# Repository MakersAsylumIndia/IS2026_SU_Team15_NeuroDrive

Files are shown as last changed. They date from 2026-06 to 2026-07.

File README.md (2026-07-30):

# IS2026 Spring - NeuroDrive

EMG-controlled robot car that uses muscle signals to drive, turn, and navigate without any traditional controller. By converting tiny electrical impulses from the human body into movement commands, we bridge the gap between humans and machines in a fun and innovative way.
"Move your muscles. Move the machine." 💪🤖

# Prototype Photos

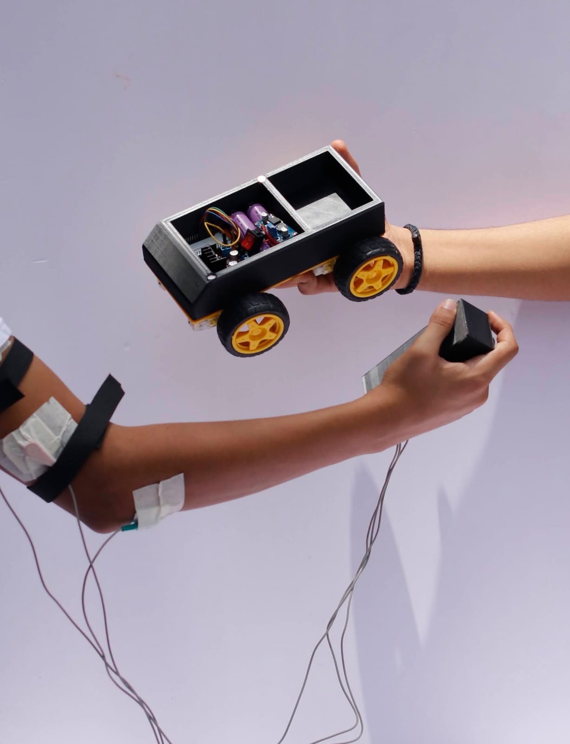
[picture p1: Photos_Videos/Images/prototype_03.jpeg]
Prototype


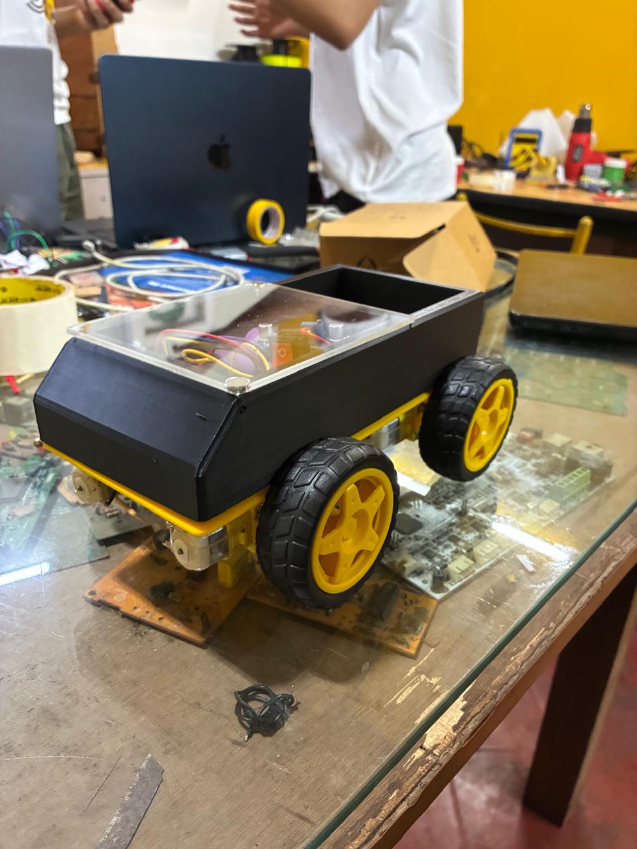
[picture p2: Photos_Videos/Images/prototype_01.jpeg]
Prototype


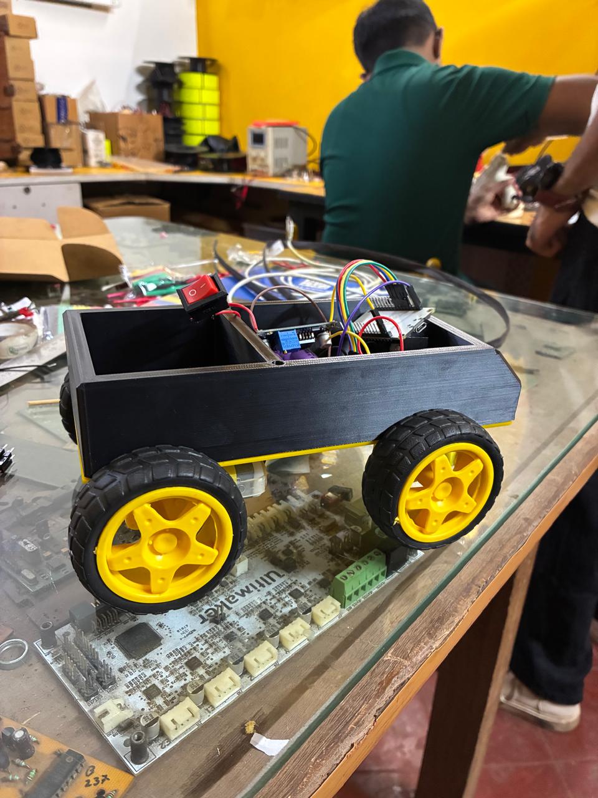
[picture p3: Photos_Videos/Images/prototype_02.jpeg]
Prototype


# CAD RENDER

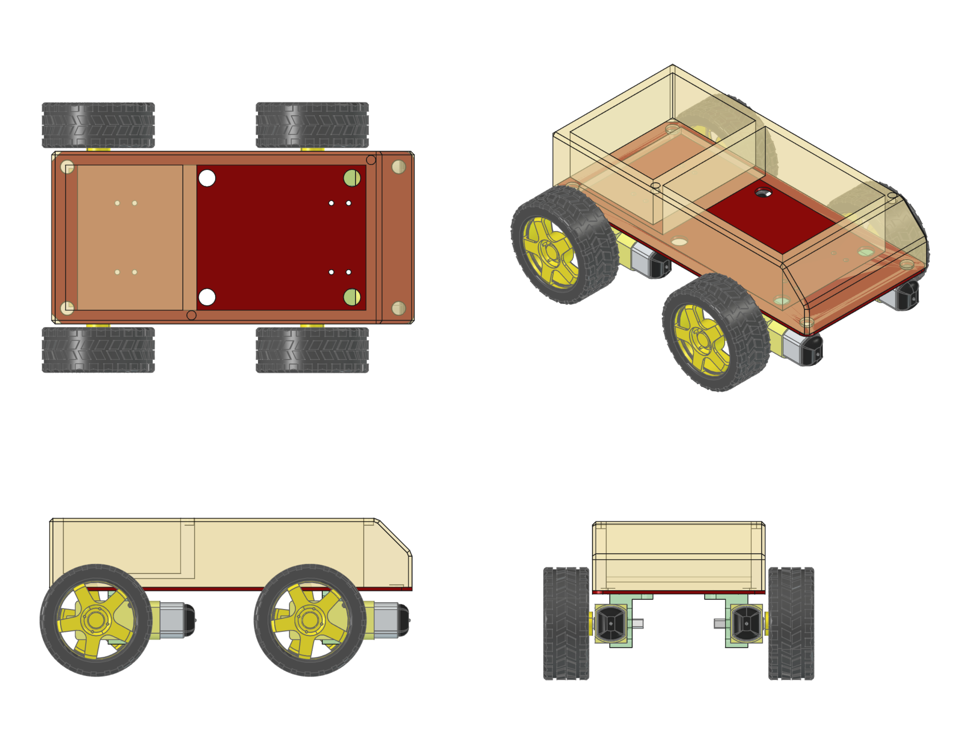
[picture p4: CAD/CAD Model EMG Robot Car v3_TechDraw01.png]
NeuroDrive CAD Render


## License

Licenses

<a href="LICENSE.md">Open Source Licenses Facts</a>

#### Hardware
CERN Open Hardware License Version 2 - Strongly Reciprocal ([CERN-OHL-S-2.0](https://spdx.org/licenses/CERN-OHL-S-2.0.html)).

#### Software
MIT open source [license](http://opensource.org/licenses/MIT).

#### Documentation:
<br />This work is licensed under a <a rel="license" href="http://creativecommons.org/licenses/by/4.0/">Creative Commons Attribution 4.0 International License</a>.

---

## 📬 Contact/Team

> _List team members and contact emails or GitHub profiles._

[Aaliya Thakker](https://github.com/Aaliya17)

[Abhay Gupta](https://github.com/abhiguppta-spec)

[Kashvi Mummaneni](https://github.com/Kashvi-Mm)

[Reyansh Bhimrajka](https://github.com/rbhimrajka)

[Maker's Asylum](https://github.com/makersasylum)

[Anool](https://github.com/Anool)
> 
> ---

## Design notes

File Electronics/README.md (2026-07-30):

The Circuit Diagram can be viewed at this URL :
https://app.cirkitdesigner.com/project/f359c818-f60a-4dbf-a67e-0d322c175c05

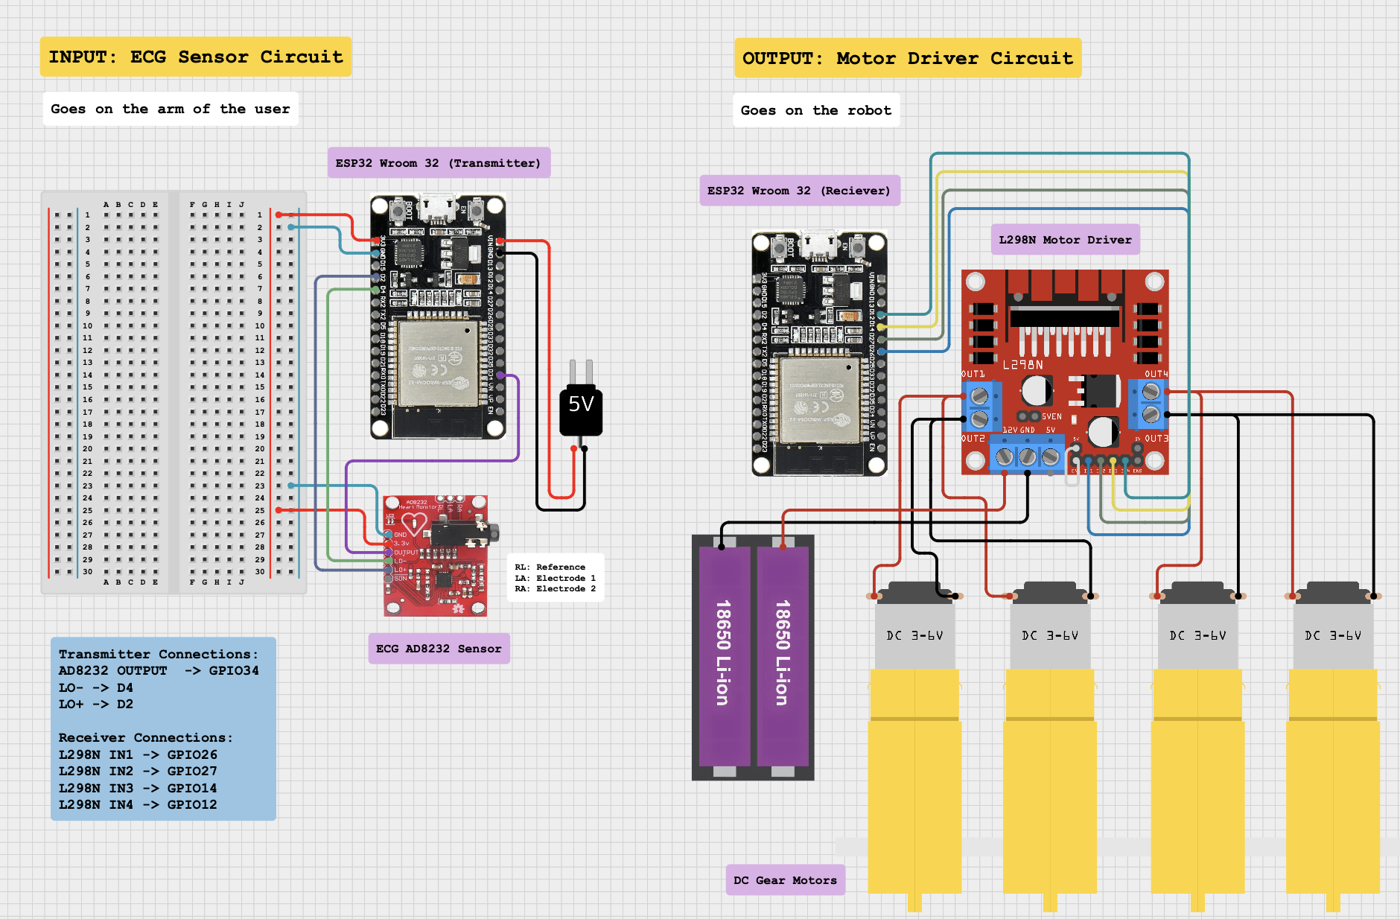
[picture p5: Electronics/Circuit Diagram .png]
NeuroDrive CAD Render


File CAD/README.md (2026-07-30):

# CAD RENDER

- 3D print the ENCLOSURE STEP file from the 3d_prints folder
- 3D print the MOTOR MOUNTS STEP files from the 3d_prints folder (two each for left and right)
- Laser cut the CHASSIS base from the laser_cut folder (Acrylic, 3mm or 5mm)
- Use 8mm magnets to attach ENCLOSURE to CHASSIS

NeuroDrive CAD Render

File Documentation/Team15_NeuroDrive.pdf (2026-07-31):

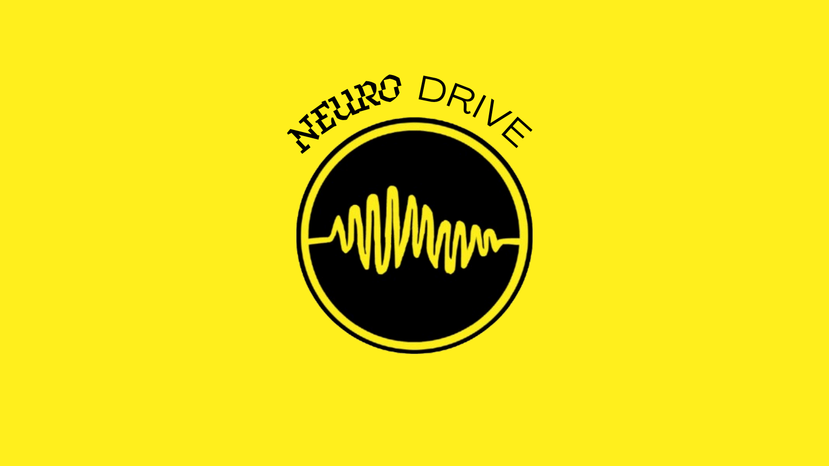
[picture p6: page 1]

# DRIVE

# NEURO

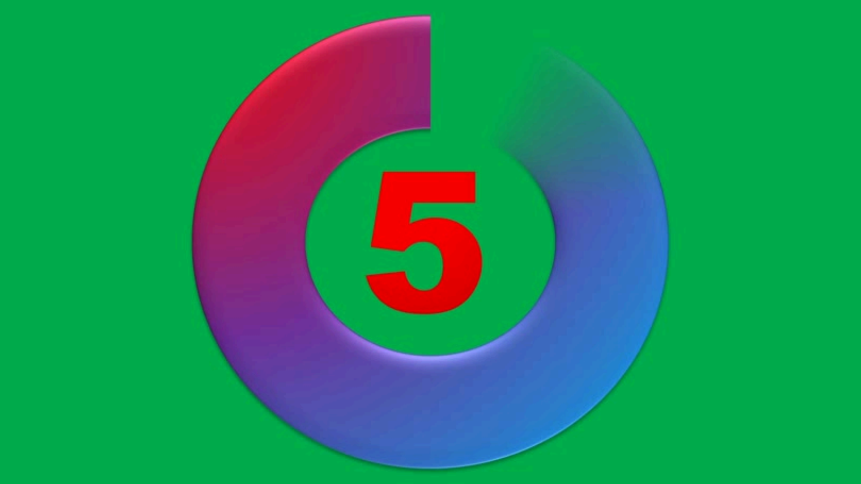
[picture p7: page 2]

# The World'

s Most Revolutionary, Groundbreaking,

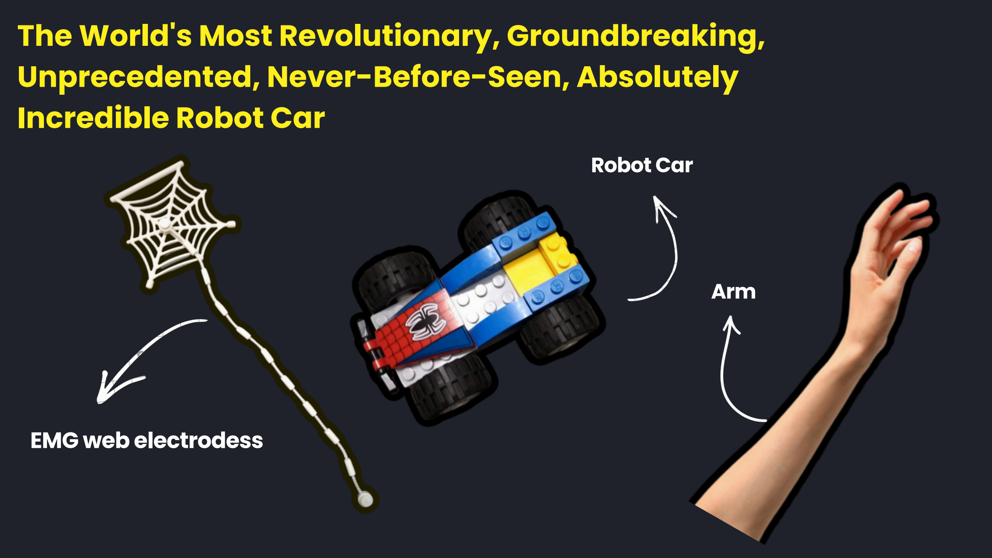
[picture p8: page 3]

# Unprecedented, Never-Before-Seen, Absolutely Incredible Robot Car

# EMG web electrodess

# Robot Car

# Arm

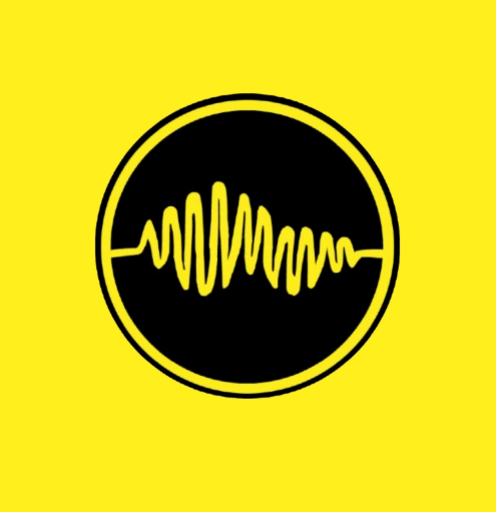
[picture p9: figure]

# MEET OURTEAM

# Aaliya Thakker

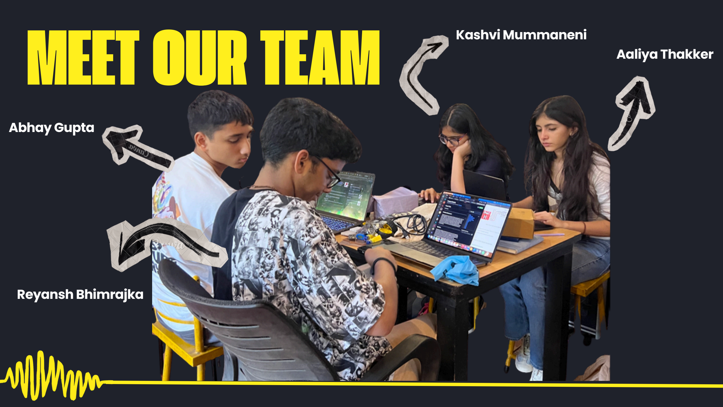
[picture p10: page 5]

# Kashvi Mummaneni

# Abhay Gupta

# Reyansh Bhimrajka

# THE PROBLEM

Everyday electronic devices like phones, remotes, controllers, robots; require hands,

# fingers, and precise motor control to operate. For people with conditions like paralysis, muscular dystrophy, ALS, or limb loss, this creates a complete barrier to

independent interaction with technology.

# However, most assistive technologies are either too expensive, too complex, or

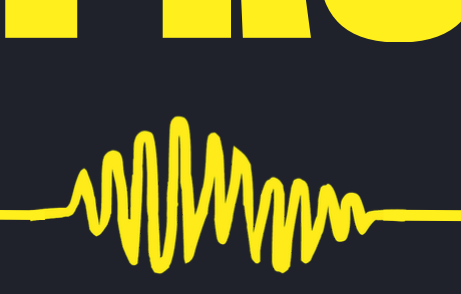
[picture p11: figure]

require full physical movement to operate.

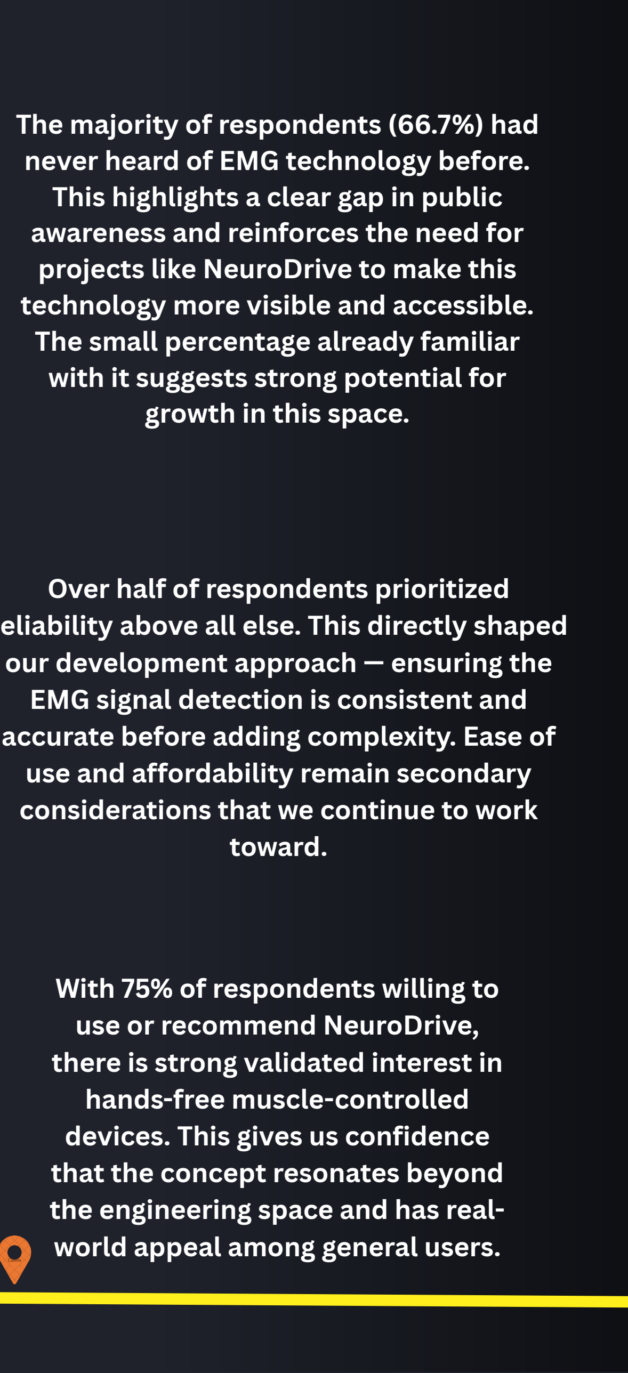
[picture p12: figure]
The majority of respondents (66.7%) had never heard of EMG technology before. This highlights a clear gap in public awareness and reinforces the need for projects like NeuroDrive to make this technology more visible and accessible. The small percentage already familiar with it suggests strong potential for growth in this space.; Over half of respondents prioritized; our development approach — ensuring the EMG signal detection is consistent and; use and affordability remain secondary considerations that we continue to work toward.; With 75% of respondents willing to use or recommend NeuroDrive, there is strong validated interest in hands-free muscle-controlled devices. This gives us confidence that the concept resonates beyond the engineering space and has real- world appeal among general users.
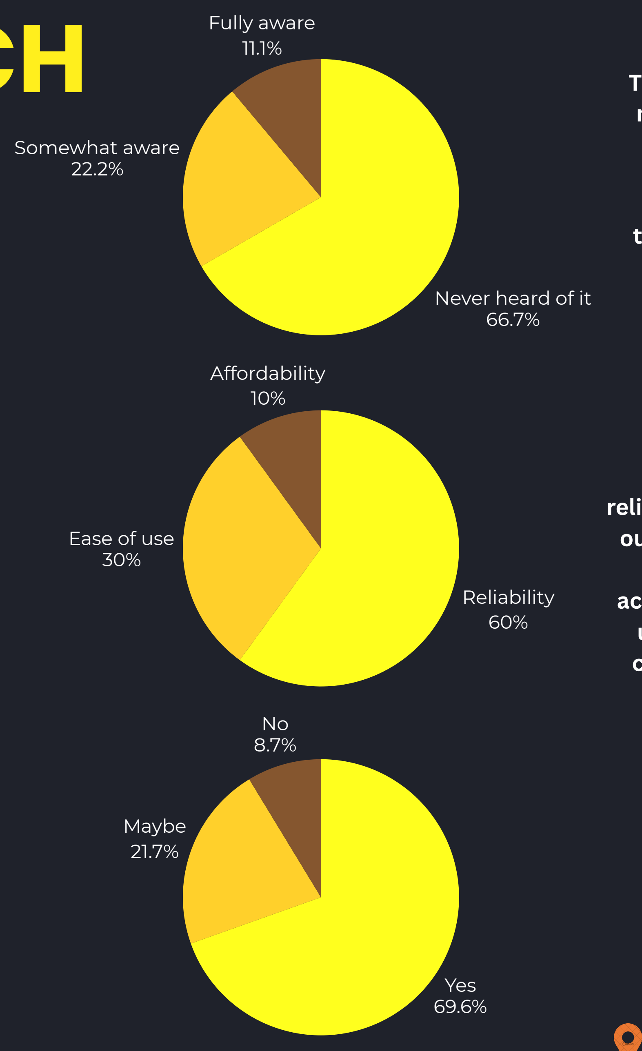
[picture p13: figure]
Yes 69.6%; Maybe 21.7%; Reliability 60%; Ease of use 30%; Affordability 10%; Never heard of it 66.7%; Somewhat aware 22.2%; Fully aware 11.1%
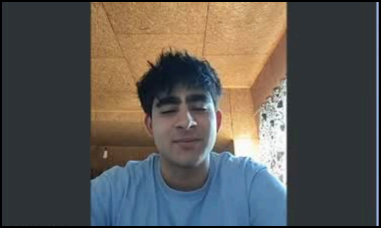
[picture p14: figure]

reliability above all else. This directly shaped

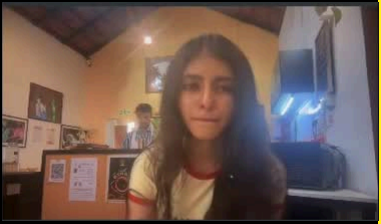
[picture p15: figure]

accurate before adding complexity. Ease of

# PRIMARY RESEARCH

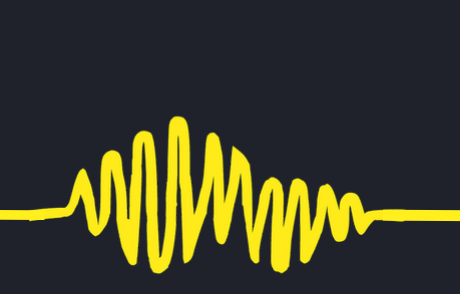
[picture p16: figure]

N

e

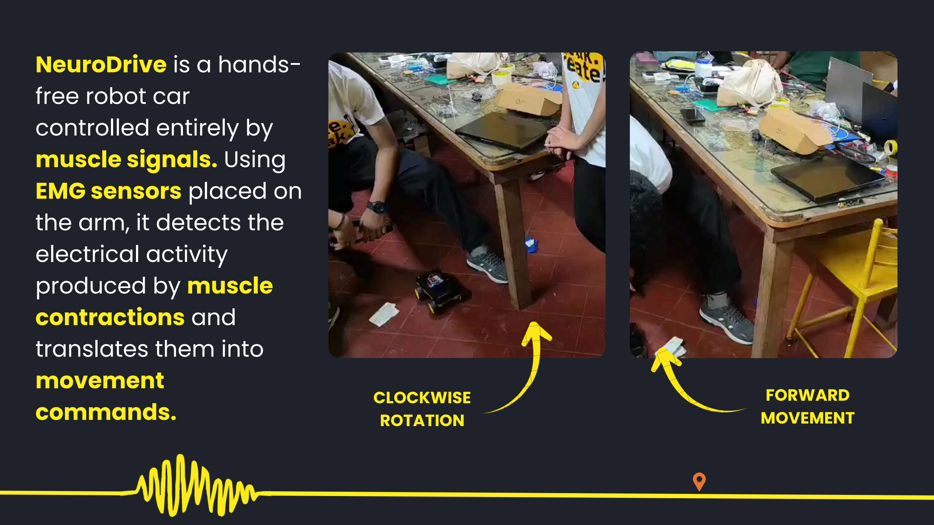
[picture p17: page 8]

u

r

o

D

r

i

v

# e is

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
# olle

d

e

n

# tir

# ely

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
# sin

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
# pla

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
, it

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
# ele

c

t

# ric

# al a

c

# tivit

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
# sla

t

e

s

t

h

e

# m in

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
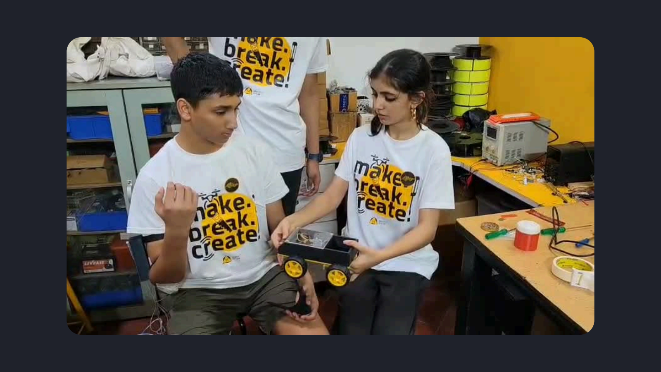
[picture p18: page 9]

# HARDWARE BREAKDOWN

## Li-ion Batteries

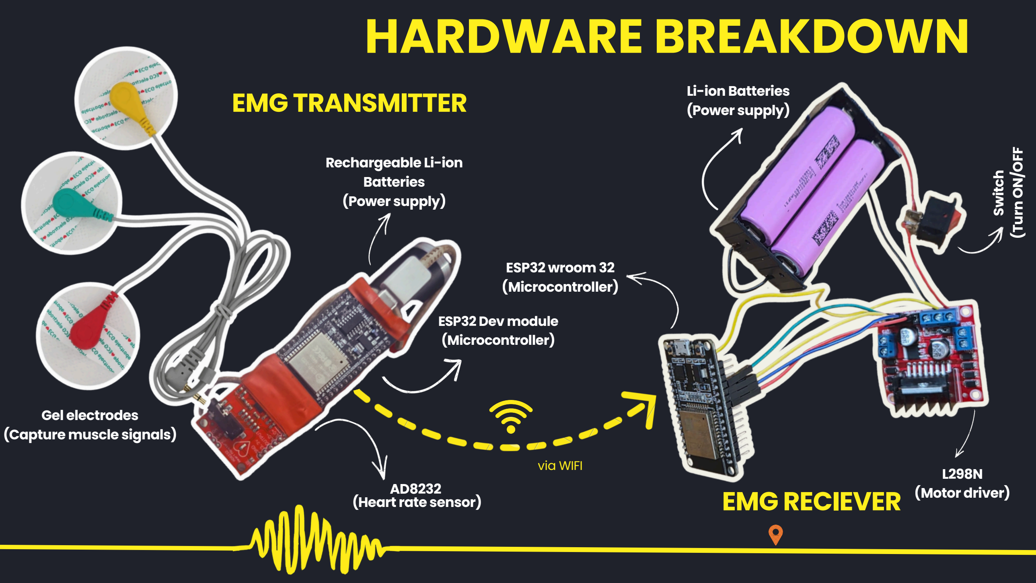
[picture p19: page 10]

L298N

## (Motor driver)

## ESP32 wroom32 (Microcontroller)

## (Power supply)

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
# EMG RECIEVER

# EMG TRANSMITTER

## ESP32 Devmodule (Microcontroller)

## Rechargeable Li-ion Batteries (Power supply)

## Gel electrodes (Capturemuscle signals)

AD8232

## (Heart rate sensor)

### via WIFI

# TECHNICAL OVERVIEW OF HOW NEURO DRIVE WORKS

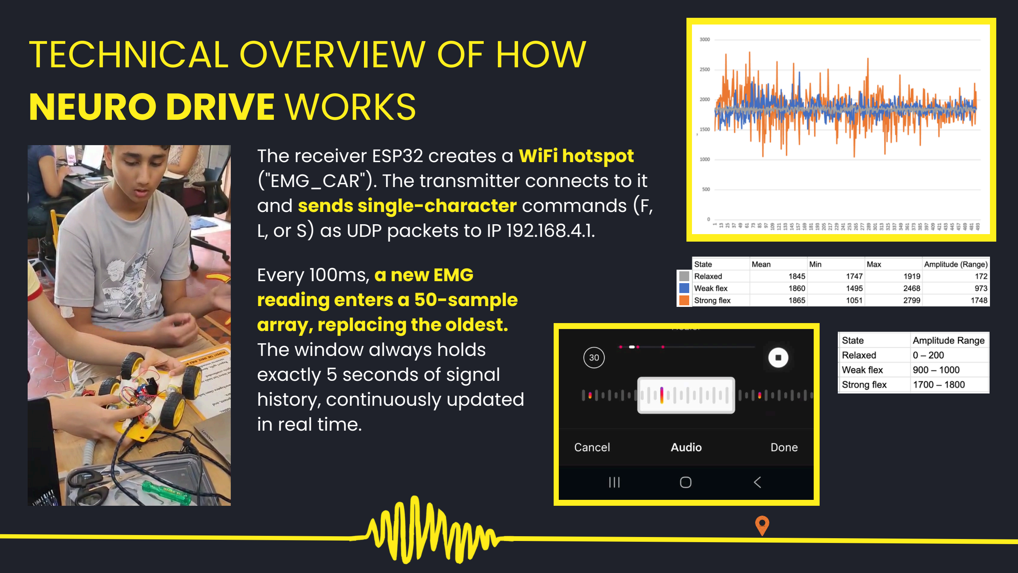
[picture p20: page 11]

# The receiver ESP32 creates a WiFi hotspot ("EMG_CAR"). The transmitter connects to it

and sends single-character commands (F, L, or S) as UDP packets to IP 192.168.4.1.

# Every 100ms, a new EMG reading enters a 50-sample

array, replacing the oldest.

# The window always holds exactly 5 seconds of signal history, continuously updated

in real time.

# DESIGN

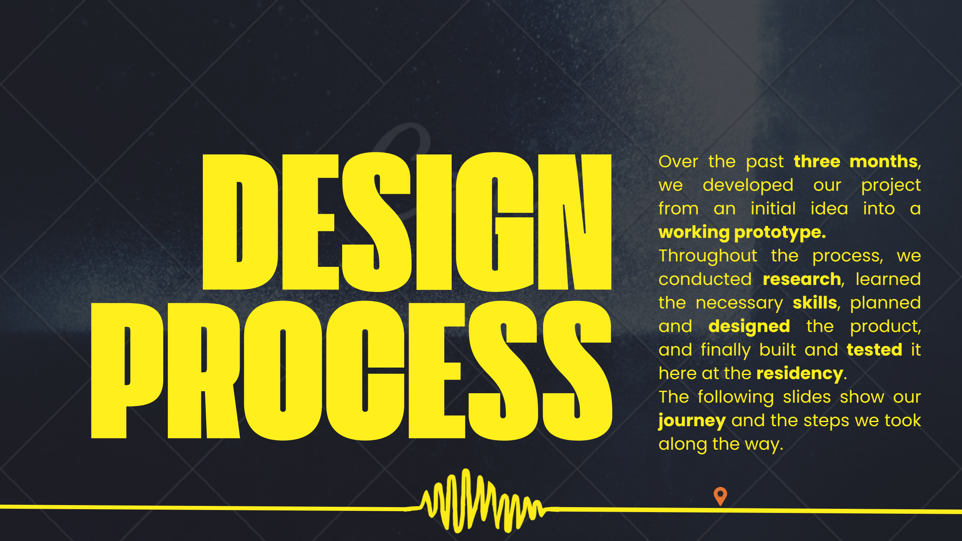
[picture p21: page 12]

Over the past three months,

# we developed our project from an initial idea into a

working prototype.

# Throughout the process, we conducted research, learned the necessary skills, planned

and designed the product,

# and finally built and tested it

here at the residency.

# The following slides show our journey and the steps we took

along the way.

# PROCESS

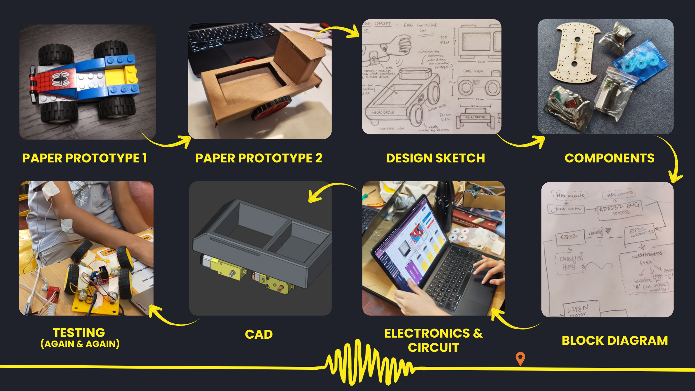
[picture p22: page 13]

PAPER PROTOTYPE 1 | PAPER PROTOTYPE 2 | DESIGN SKETCH | COMPONENTS

# BLOCK DIAGRAM

# ELECTRONICS & CIRCUIT

TESTING | CAD

## (AGAIN & AGAIN)

# ECG SENSOR

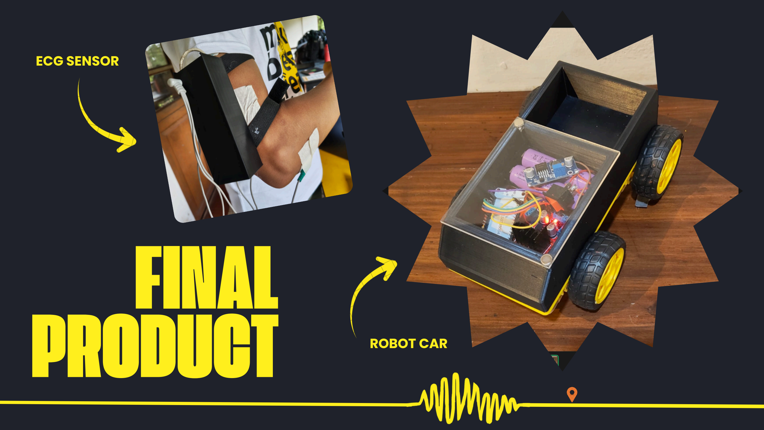
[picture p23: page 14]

# ROBOT CAR

# FINAL PRODUCT

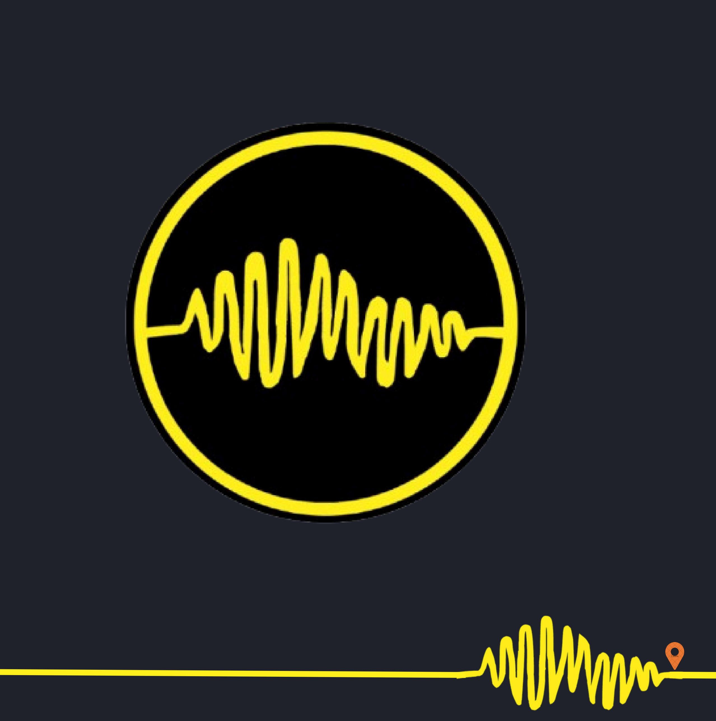
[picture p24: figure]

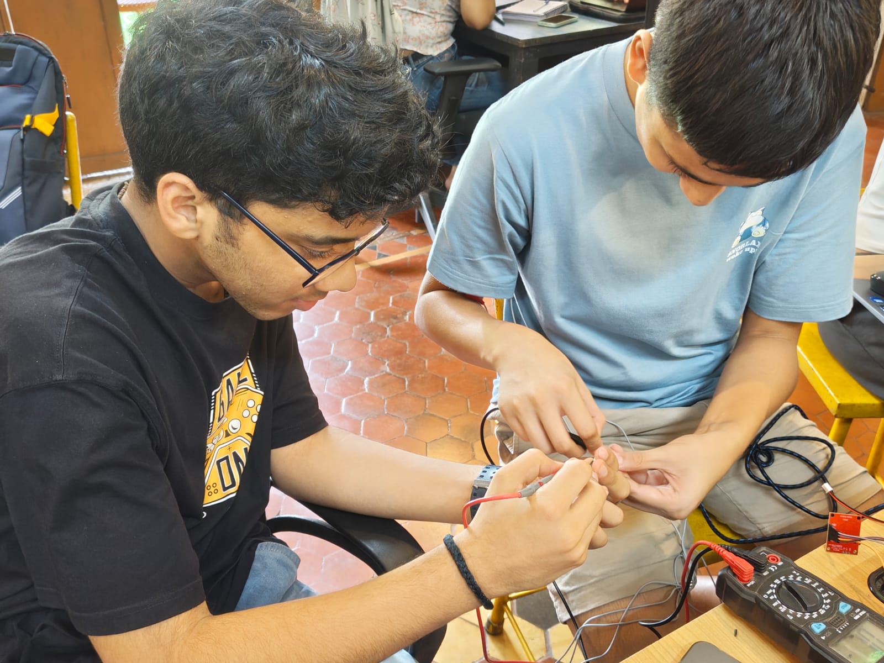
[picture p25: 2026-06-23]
Photos_Videos/Images/Electronics.jpeg

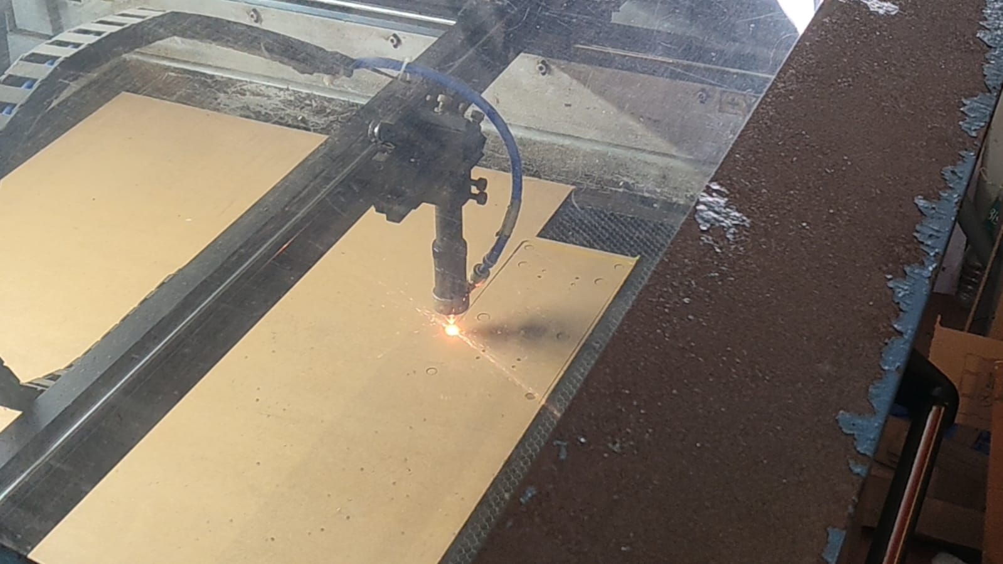
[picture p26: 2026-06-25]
Photos_Videos/Images/Laser Cutting Chassis.jpeg

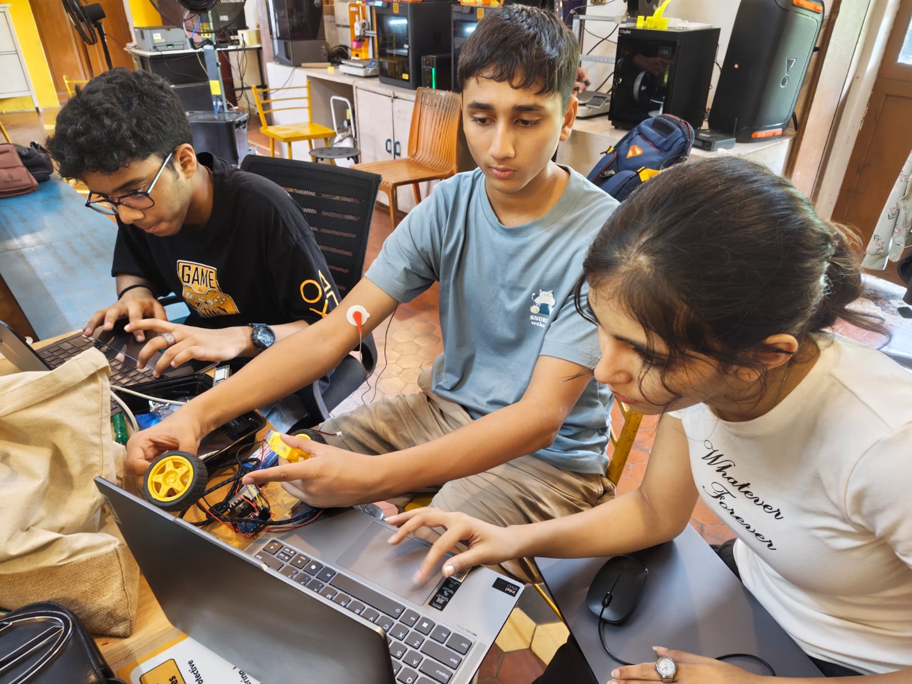
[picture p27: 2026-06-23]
Photos_Videos/Images/Electronics 2.jpeg

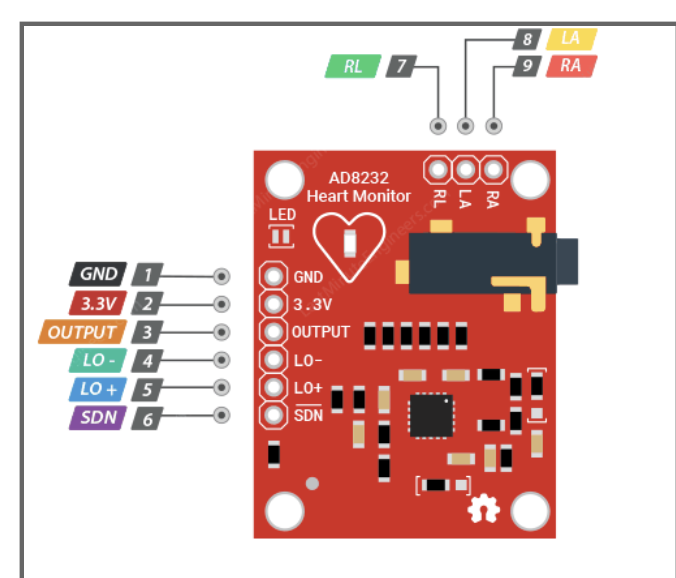
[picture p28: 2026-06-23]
Electronics/AD8232 Pinouts.png

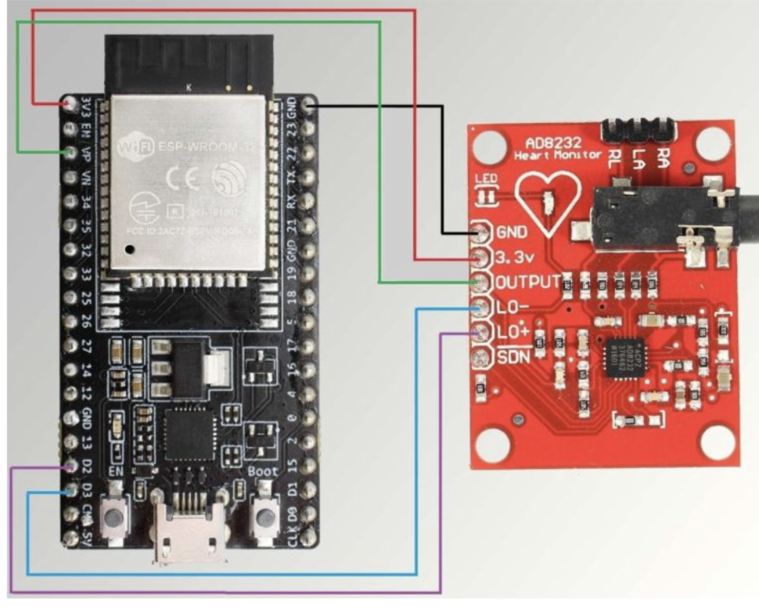
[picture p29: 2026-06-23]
Electronics/ESP32 to AD8232 Connection .png

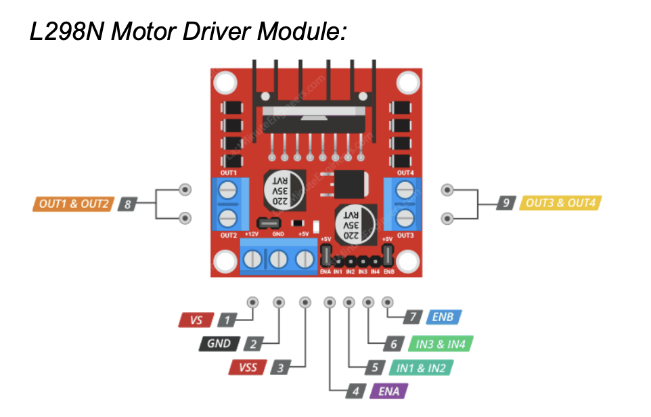
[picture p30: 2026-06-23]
Electronics/L298N Driver Pinouts.png

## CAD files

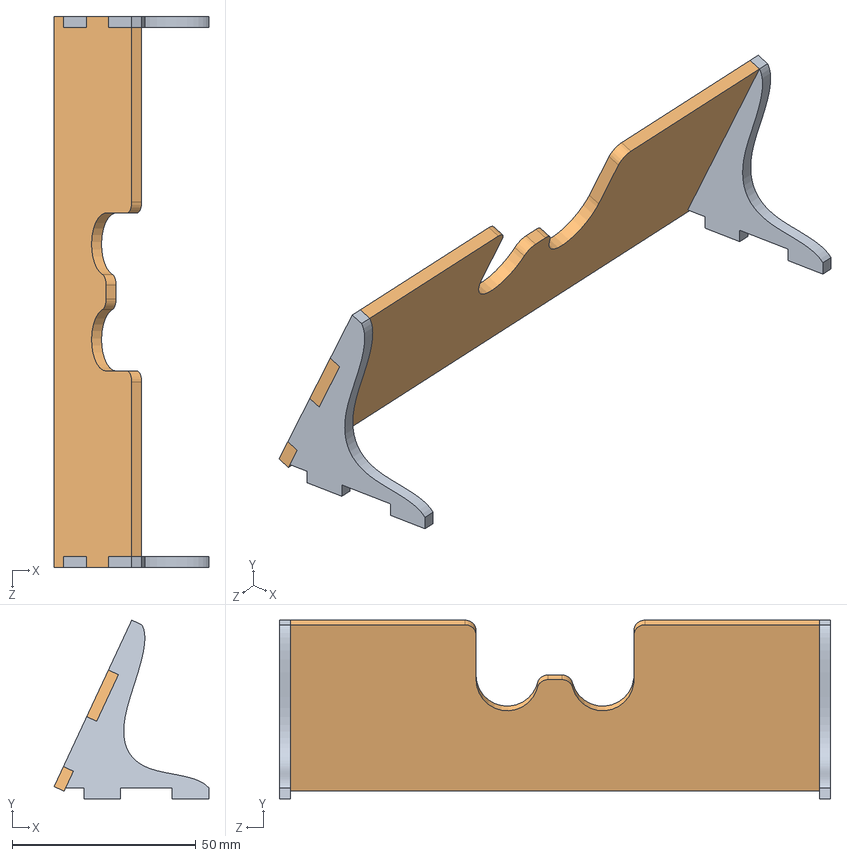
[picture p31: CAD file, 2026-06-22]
CAD/assets/sumo-bot-15x15cm-1.snapshot.4/Solid/Defensa.SLDASM
42.1 x 48.7 x 150.0 mm
SoporteDefensa_dm x 2
Defensa_dm

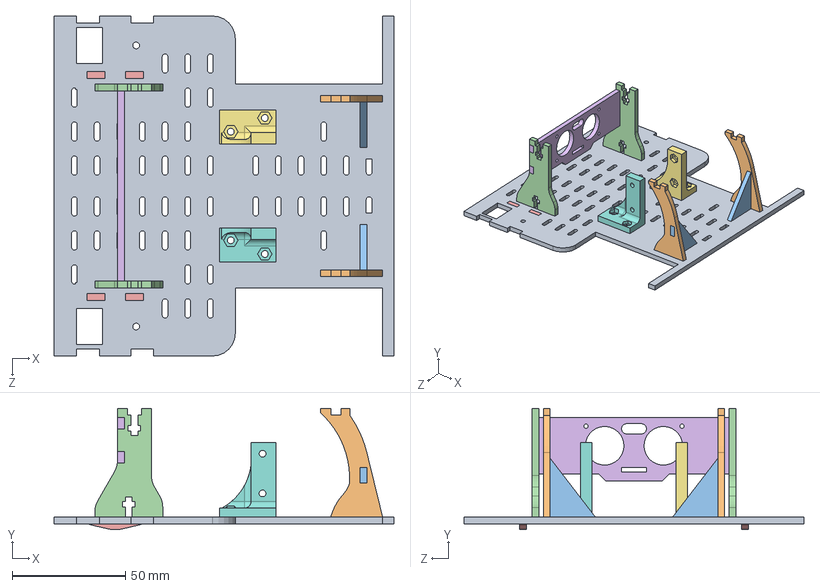
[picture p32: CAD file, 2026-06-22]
CAD/assets/sumo-bot-15x15cm-1.snapshot.4/Solid/Base_inferior.SLDASM
150.0 x 53.5 x 150.0 mm
base1_dm
SoporteBateria_dm x 2
NervioBateria_dm x 2
SoporteArduino1_dm x 2
Ski x 2
SoporteSensorUltrasonidos
SoporteMotor
SimetríaSoporteMotor

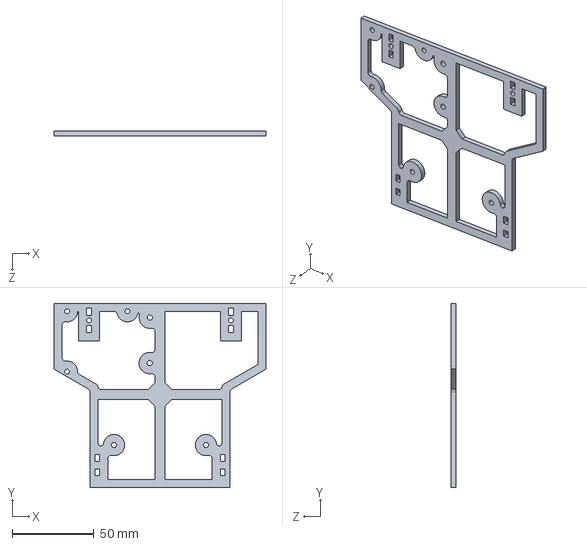
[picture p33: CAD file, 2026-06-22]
CAD/assets/sumo-bot-15x15cm-1.snapshot.4/Solid/Base_superior.SLDASM
130.0 x 113.1 x 3.00 mm

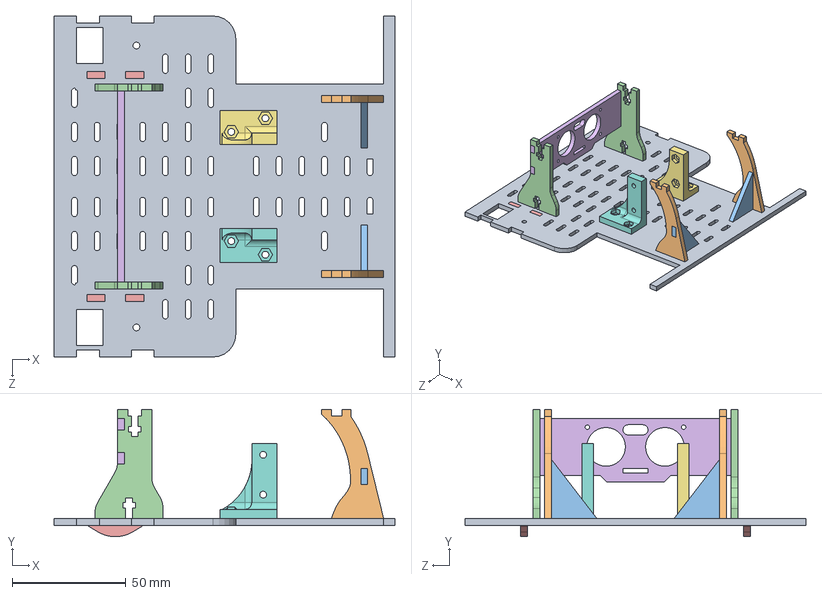
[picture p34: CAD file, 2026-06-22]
CAD/assets/sumo-bot-15x15cm-1.snapshot.4/Solid/Base1_electronica.SLDASM
150.0 x 56.0 x 150.0 mm
base1_dm
SoporteBateria_dm x 2
NervioBateria_dm x 2
SoporteArduino1_dm x 2
Ski x 2
SoporteSensorUltrasonidos
SoporteMotor
SimetríaSoporteMotor

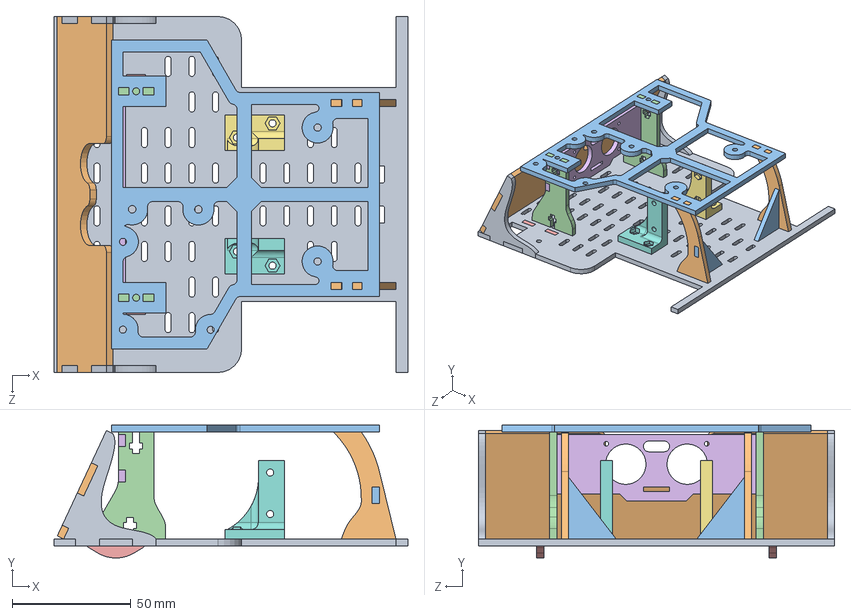
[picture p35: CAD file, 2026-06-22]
CAD/assets/sumo-bot-15x15cm-1.snapshot.4/Solid/_Sumo.SLDASM
149.0 x 56.0 x 150.0 mm
base1_dm
SoporteBateria_dm x 2
NervioBateria_dm x 2
SoporteArduino1_dm x 2
Ski x 2
SoporteSensorUltrasonidos
SoporteMotor
SimetríaSoporteMotor
SoporteDefensa_dm x 2
Defensa_dm
base2_dm

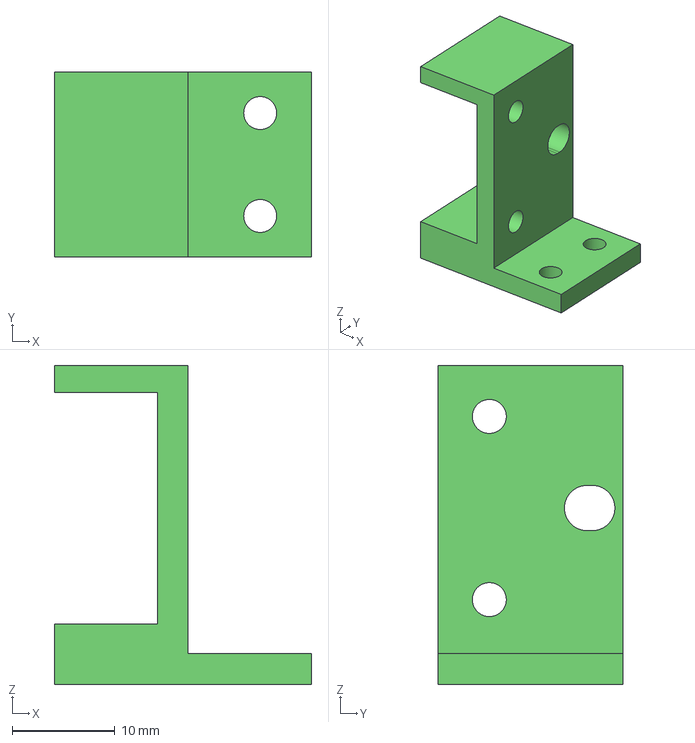
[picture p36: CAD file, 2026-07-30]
CAD/3d_prints/gesture_bot-motor_mount_02.step
25.0 x 18.0 x 31.0 mm

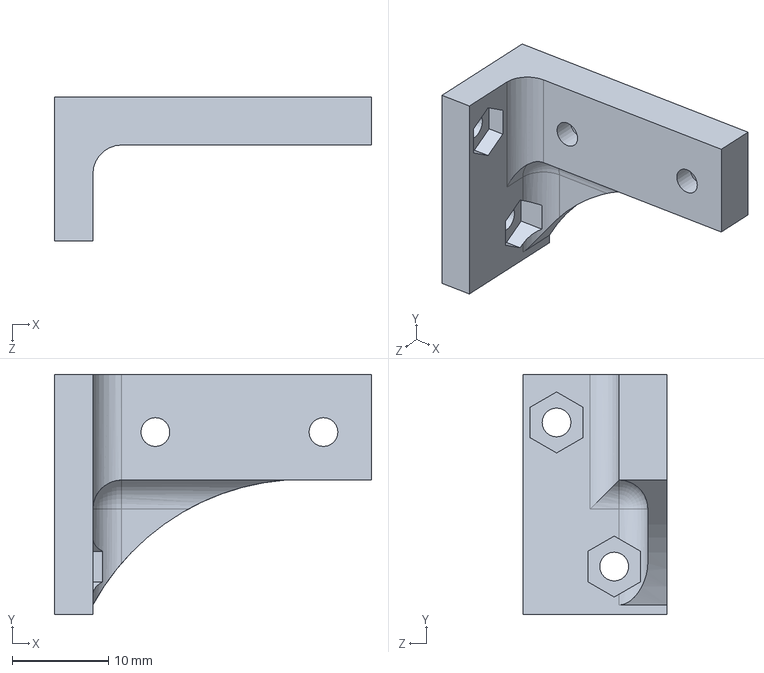
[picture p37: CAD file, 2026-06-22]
CAD/assets/sumo-bot-15x15cm-1.snapshot.4/Solid/SoporteMotor.SLDPRT
33.0 x 25.0 x 15.0 mm

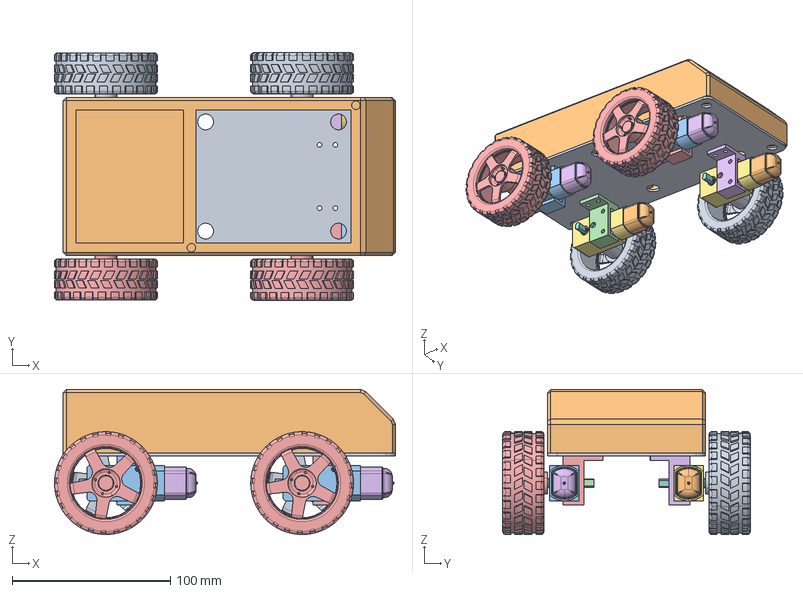
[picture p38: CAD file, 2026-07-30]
CAD/CAD Model EMG Robot Car v3.FCStd
215.5 x 156.5 x 91.6 mm
Chassis
Enclosure
Real Bo Motor Gear Box004
Shaft004
Real Wheel004
Real Bo Motor Frame012
Real Bo Motor Gear Box
Shaft
Real Wheel
Real Bo Motor Frame
Real Bo Motor Gear Box005
Shaft005
Real Wheel005
Real Bo Motor Frame013
Real Bo Motor Gear Box006
Shaft006
Real Wheel006
Real Bo Motor Frame014
motor_mount_01
motor_mount_03 (Mirror #1)
motor_mount_02
motor_mount_04 (Mirror #1)

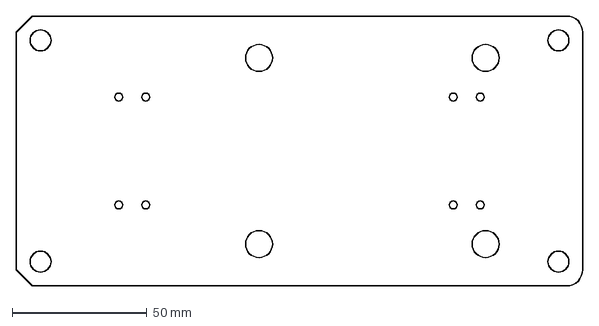
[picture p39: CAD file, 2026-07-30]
CAD/laser_cut/gesture_bot-Chassis_2DView.dxf
210.0 x 100.0 mm

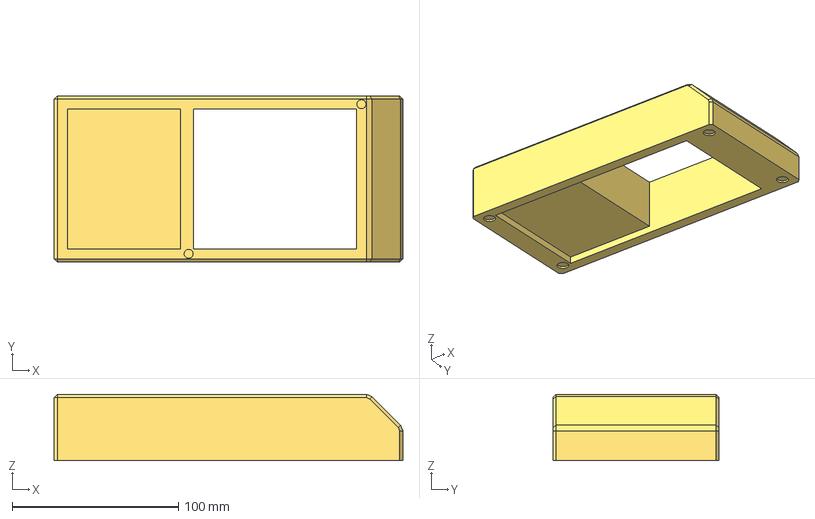
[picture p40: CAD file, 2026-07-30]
CAD/3d_prints/CAD Model EMG Robot Car v3-Enclosure.step
210.0 x 100.0 x 40.0 mm

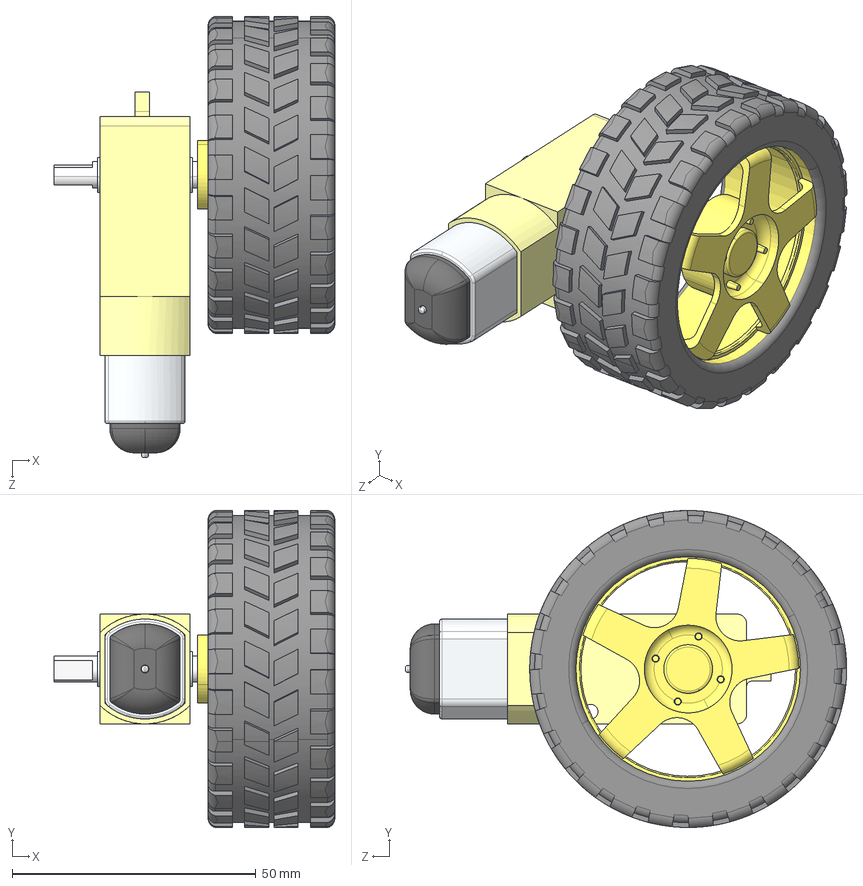
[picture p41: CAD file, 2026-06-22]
CAD/assets/Real Bo Motor With Wheel.step
57.6 x 65.0 x 90.5 mm
Real Bo Motor Gear Box
Shaft
Real Wheel
Real Bo Motor Frame

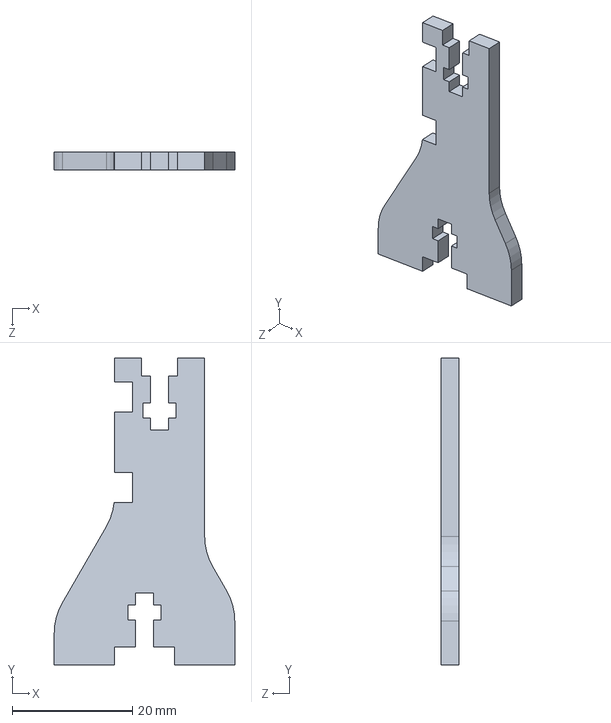
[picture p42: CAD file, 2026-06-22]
CAD/assets/sumo-bot-15x15cm-1.snapshot.4/Solid/SoporteArduino1_dm.SLDPRT
30.0 x 51.0 x 3.00 mm

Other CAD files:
CAD/assets/sumo-bot-15x15cm-1.snapshot.4/Files/Defensa_dm.DWG
CAD/assets/sumo-bot-15x15cm-1.snapshot.4/Files/SimetríaSoporteMotor.STL
CAD/3d_prints/gesture_bot-motor_mount_01.step
CAD/assets/sumo-bot-15x15cm-1.snapshot.4/Files/SoporteArduino1_dm.DWG
CAD/assets/sumo-bot-15x15cm-1.snapshot.4/Solid/SimetríaSoporteMotor.SLDPRT
CAD/assets/sumo-bot-15x15cm-1.snapshot.4/Files/SoporteBateria_dm.DWG
CAD/assets/18650 Battery Holder v5.step
CAD/assets/sumo-bot-15x15cm-1.snapshot.4/Files/NervioBateria_dm.DWG
CAD/assets/sumo-bot-15x15cm-1.snapshot.4/Files/Ski.DWG
CAD/assets/sumo-bot-15x15cm-1.snapshot.4/Files/SoporteDefensa_dm.DWG
CAD/assets/sumo-bot-15x15cm-1.snapshot.4/Files/SoporteMotor.STL
CAD/assets/sumo-bot-15x15cm-1.snapshot.4/Files/SoporteSensorUltrasonidos.DWG
CAD/assets/sumo-bot-15x15cm-1.snapshot.4/Files/base1_dm.DWG
CAD/assets/sumo-bot-15x15cm-1.snapshot.4/Files/base2_dm.DWG
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

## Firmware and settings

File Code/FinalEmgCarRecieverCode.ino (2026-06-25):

// EMG Car Receiver — ESP32 WROOM-32 + L298N
//
// L298N IN1 -> GPIO26  (Left motor)
// L298N IN2 -> GPIO27  (Left motor)
// L298N IN3 -> GPIO14  (Right motor)
// L298N IN4 -> GPIO12  (Right motor)
// L298N ENA -> 5V (always enabled)
// L298N ENB -> 5V (always enabled)

#include "BluetoothSerial.h"
BluetoothSerial bt;

void setup() {
  Serial.begin(115200);
  bt.begin("EMG_CAR");
  Serial.print("MAC: ");
  Serial.println(ESP.getEfuseMac(), HEX);
}

void loop() {}

// ======================================================
// Motor Control
// ======================================================

void motorForward()
{
  digitalWrite(IN1, HIGH); digitalWrite(IN2, LOW);
  digitalWrite(IN3, HIGH); digitalWrite(IN4, LOW);
}

void motorAnticlockwise()
{
  // Left motor backward, right motor forward → spins anticlockwise
  digitalWrite(IN1, LOW);  digitalWrite(IN2, HIGH);
  digitalWrite(IN3, HIGH); digitalWrite(IN4, LOW);
}

void motorStop()
{
  digitalWrite(IN1, LOW); digitalWrite(IN2, LOW);
  digitalWrite(IN3, LOW); digitalWrite(IN4, LOW);
}

// ======================================================
// Setup
// ======================================================

void setup()
{
  Serial.begin(115200);

  pinMode(IN1, OUTPUT); pinMode(IN2, OUTPUT);
  pinMode(IN3, OUTPUT); pinMode(IN4, OUTPUT);
  motorStop();

  bt.begin("EMG_CAR");
  Serial.println("Bluetooth started. Waiting for connection...");
}

// ======================================================
// Main Loop
// ======================================================

void loop()
{
  if (bt.available())
  {
    char cmd = bt.read();
    Serial.print("[CMD] "); Serial.println(cmd);

    if      (cmd == 'F') { motorForward();       Serial.println("FORWARD");       }
    else if (cmd == 'L') { motorAnticlockwise(); Serial.println("ANTICLOCKWISE"); }
    else if (cmd == 'S') { motorStop();          Serial.println("STOP");          }
  }
}

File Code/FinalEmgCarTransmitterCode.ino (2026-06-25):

// EMG Transmitter — ESP32 WROOM-32 + AD8232
// WiFi station mode — connects to receiver hotspot, sends UDP commands
//
// AD8232 OUTPUT -> GPIO34
// AD8232 LO-    -> GPIO4
// AD8232 LO+    -> GPIO5
//
// Peak-to-peak over 50 samples, 100ms delay:
//


#include <WiFi.h>
#include <WiFiUdp.h>

const char* AP_SSID     = "EMG_CAR";
const char* AP_PASS     = "12345678";
const char* RECEIVER_IP = "192.168.4.1";
const int   UDP_PORT    = 4210;

WiFiUDP udp;

const int EMG_PIN  = 34;
const int LO_MINUS =  4;
const int LO_PLUS  =  5;

const int   WINDOW_SIZE      = 40;
const float RELAXED_MAX      = 250.0;
const float WEAK_MIN         = 500.0;
const float WEAK_MAX         = 800.0;
const float STRONG_MIN       = 1050.0;
const float STRONG_MAX       = 1800.0;

int window[WINDOW_SIZE];
int windowIndex = 0;
bool windowFull = false;

char lastCommand = 'S';

// ======================================================
// Send command only on state change
// ======================================================
void sendCommand(char cmd)
{
  if (cmd != lastCommand)
  {
    udp.beginPacket(RECEIVER_IP, UDP_PORT);
    udp.write((uint8_t)cmd);
    udp.endPacket();

    lastCommand = cmd;
    Serial.print("[SENT] "); Serial.println(cmd);
  }
}

// ======================================================
// Compute peak-to-peak of rolling window
// ======================================================
float computePeakToPeak()
{
  int count = windowFull ? WINDOW_SIZE : windowIndex;
  if (count == 0) return 0;

  int maxVal = window[0];
  int minVal = window[0];

  for (int i = 1; i < count; i++)
  {
    if (window[i] > maxVal) maxVal = window[i];
    if (window[i] < minVal) minVal = window[i];
  }

  return maxVal - minVal;
}

// ======================================================
// Setup
// ======================================================
void setup()
{
  Serial.begin(115200);
  pinMode(LO_MINUS, INPUT);
  pinMode(LO_PLUS,  INPUT);

  WiFi.begin(AP_SSID, AP_PASS);
  Serial.print("Connecting to EMG_CAR hotspot");

  while (WiFi.status() != WL_CONNECTED)
  {
    delay(500);
    Serial.print(".");
  }

  Serial.println();
  Serial.println("WiFi connected!");
  Serial.print("IP: "); Serial.println(WiFi.localIP());

  udp.begin(UDP_PORT);

  Serial.println("RELAXED     = Stop");
  Serial.println("WEAK FLEX   = Anticlockwise");
  Serial.println("STRONG FLEX = Forward");
  Serial.println("System Running...");
}

// ======================================================
// Main Loop
// ======================================================
void loop()
{
  if (digitalRead(LO_PLUS) == HIGH || digitalRead(LO_MINUS) == HIGH)
  {
    Serial.println("LEADS OFF — check electrodes");
    sendCommand('S');
    delay(100);
    return;
  }

  window[windowIndex] = analogRead(EMG_PIN);
  windowIndex++;

  if (windowIndex >= WINDOW_SIZE)
  {
    windowIndex = 0;
    windowFull  = true;
  }

  float peakToPeak = computePeakToPeak();

  Serial.println(peakToPeak);

  if (peakToPeak >= STRONG_MIN && peakToPeak <= STRONG_MAX)
  {
    Serial.println("STRONG FLEX — ANTICLOCKWISE");
    sendCommand('L');;
  }
  else if (peakToPeak >= WEAK_MIN && peakToPeak <= WEAK_MAX)
  {
    Serial.println("Weak FLEX — FORWARD");
    sendCommand('F');
  }
  else if (peakToPeak <= RELAXED_MAX)
  {
    sendCommand('S');
  }

  delay(100);
}

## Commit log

2026-06-20 Add new line to BOM.csv
    [BOM.csv]
2026-06-20 Remove empty line from BOM.csv
    Remove unnecessary line from BOM.csv
    [BOM.csv]
2026-06-22 added CAD files for chassis and motor mounts
    [18650 Battery Holder v5.step, Base1_electronica.SLDASM, Base_inferior.SLDASM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]
2026-06-23 Add files via upload
    This CAD model serves as an initial reference design for our EMG-controlled robot car, OmniCircuit. The model currently includes the chassis, ESP32, DC motors, wheels, and lithium-ion battery holders. Most of these components were imported from GrabCAD and assembled to create a realistic representation of the project.
    One of the key challenges was positioning and aligning all the components within the available space on the chassis. After multiple iterations and several rounds of trial and error, we were able to create a layout that is both practical and compact.
    This model provides a clear visualization of the robot car's overall structure and gives us a reference for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
2026-07-30 repo cleanup, added CAD renders
    [CAD Model EMG Robot Car v0.FCStd, CAD Model EMG Robot Car v1.FCStd, CAD Model EMG Robot Car v2.FCStd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]
2026-07-30 Update README with CAD render and team contacts
    Added CAD render image and updated team member contacts.
2026-07-30 Update CAD README with printing and cutting instructions
    Added instructions for 3D printing and laser cutting components.
2026-07-30 Update README with prototype photos
    Added prototype photos to the README.
2026-07-30 added final prototype photo
2026-07-30 Add prototype images to README
